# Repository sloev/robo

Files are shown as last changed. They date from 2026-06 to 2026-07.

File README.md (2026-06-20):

# 🤖 BlockBot Dashboard

Welcome to the **BlockBot Dashboard**! This is a fun, visual way to build and program **anything you can imagine** using an **ESP32-S2 Mini** brain and motorized stepper muscles. 

It doesn't have to be a standard robot—you can build a **crane**, a **car**, a **catapult**, a **drawing machine**, a **conveyor belt**, or a **robotic arm**! As long as it uses the motors and sensors, you can bring it to life.

**[🌐 View the Live Dashboard Demo on GitHub Pages](https://sloev.github.io/robo/)** *(Note: Hardware connections are simulated in the web demo).*

The brain board acts as its own Wi-Fi hotspot. When you connect your phone, tablet, or computer to it, this modern dashboard pops up automatically—no internet needed!

---

## 🎨 The Three Awesome Modes

The dashboard splits the control into three visual modes. Tap the tabs at the top of the screen to switch between them:

### 🧩 1. Coding Mode (Workflow Creator)
This is your coding workspace! Click block buttons on the left to add command blocks. Drag them around to change their order, choose which motors to run, adjust speeds, and add wait times. 

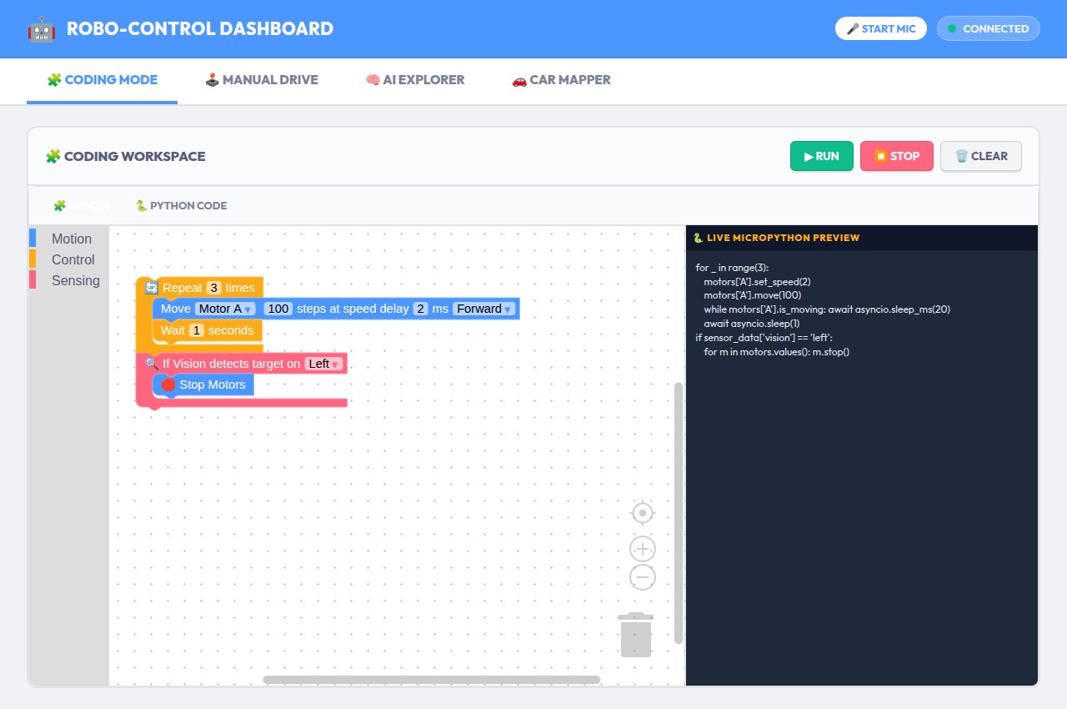
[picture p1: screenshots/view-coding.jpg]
Coding Mode in Action


**Senses & Command Blocks:**
*   **Set Motor Speed:** Adjust the speed delay of any motor on-the-fly.
*   **Stop Motors:** Instantly freeze all movement.
*   **If Vision tracks target:** Run blocks only if the camera sees your tracking marker in a certain area (Left, Center, Right).
*   **If Sound hears clap:** Run blocks only when the phone microphone detects a loud clap!

---

### 🕹️ 2. Manual Drive Mode (Steering Joysticks)
Drive your creation directly using virtual vertical joysticks! Slide them up or down to rotate cogs, move joints, or drive wheels, and release them to stop. The dashboard automatically builds a joystick for every motor you connect.

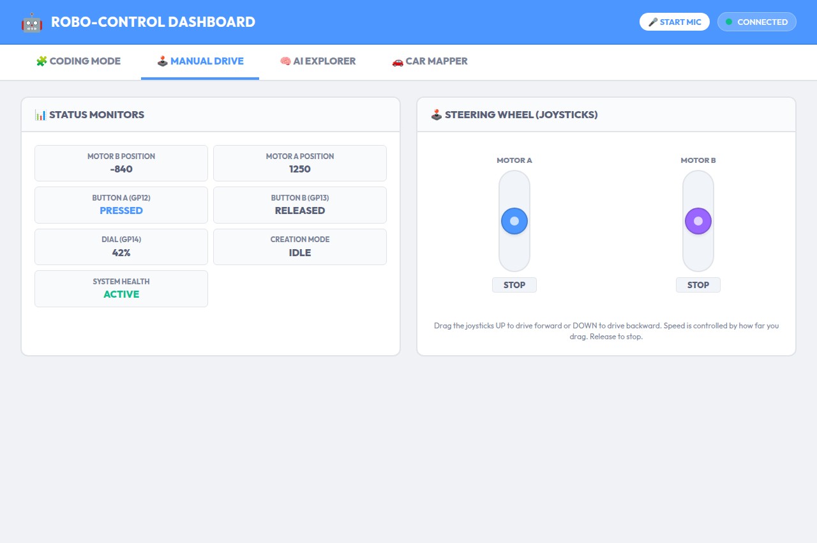
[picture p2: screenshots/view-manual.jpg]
Manual Drive in Action


---

### 🧠 3. Autonomous AI (Car Mode)
This is where the magic happens! Turn your stepper motor creation into an autonomous self-driving car using your phone's built-in sensors. By clamping your phone vertically to the front of the chassis using elastic bands and the ultra-discreet **Portrait Phone Clamp**, your phone acts as the robot's eyes, ears, and inner ear!

1.  **Sensor Fusion (Dead Reckoning):** The dashboard creates a sensor fusion of the phone's internal gyroscope, accelerometer, and magnetometer to understand its odometry and heading entirely on its own!
2.  **Learning Mode (Kinematic Discovery):** The robot wiggles its motors and uses the phone's sensors to reverse-engineer its own kinematics (whether it's built as a differential drive or an Ackermann steering setup).
3.  **Autonomous Mapping:** Place the car in the room and start the Live Mode. As the car wanders around, it uses the camera and IMU to dynamically create a live 2D map overlay of its environment.
4.  **Vision & Audio Navigation:** Using lightweight TensorFlow.js models running purely offline in the PWA, the phone actively detects obstacles using the front/rear cameras, and can react to loud noises or even utter simple sounds when encountering sudden movements or blockages!

Because all the heavy machine-learning and sensor processing happens in the browser on your powerful smartphone, the ESP32-S2 is freed up to focus entirely on perfect stepper motor coordination!

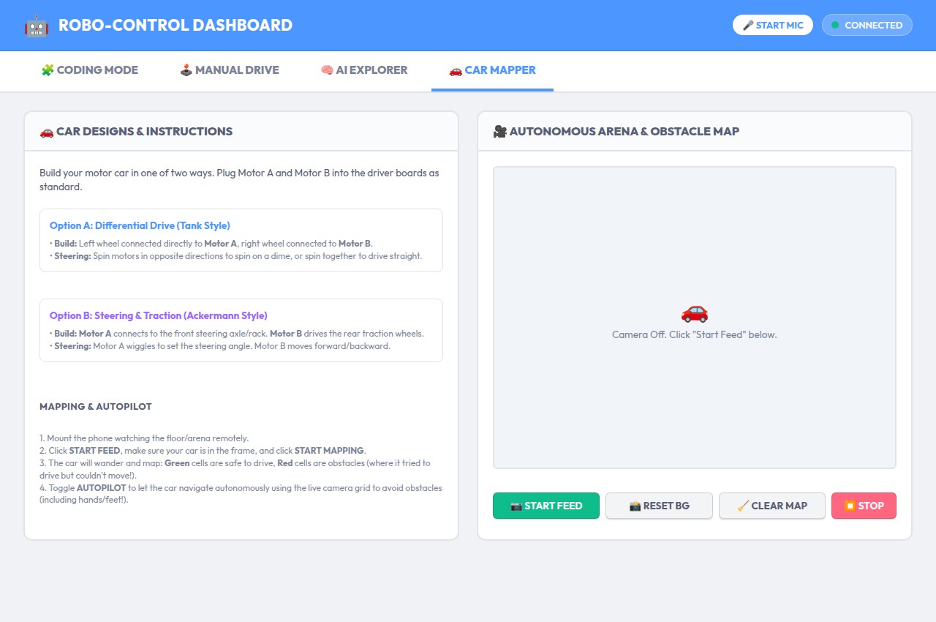
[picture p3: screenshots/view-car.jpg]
AI Car Mode in Action


---

## 🔌 How to Wire Your Creation

Here is a nice, color-coded map showing how all the parts plug together. 

```mermaid
graph TD
    %% Define Styles
    classDef esp32 fill:#4c97ff,stroke:#0d47a1,stroke-width:2px,color:#ffffff;
    classDef driver fill:#0fbd8c,stroke:#00796b,stroke-width:2px,color:#ffffff;
    classDef motor fill:#9966ff,stroke:#6a1b9a,stroke-width:2px,color:#ffffff;
    classDef power fill:#ffab19,stroke:#ff6f00,stroke-width:2px,color:#ffffff;
    classDef capacitor fill:#ff6680,stroke:#c2185b,stroke-width:2px,color:#ffffff;

    %% Nodes
    USB_PB["🔋 USB Power Bank"]:::power
    ESP_S2["🤖 ESP32-S2 Mini <br>(The Brain)"]:::esp32
    CAP["⚡ Capacitor <br>(1000µF Buffer)"]:::capacitor
    
    DRV_A["🔌 Driver Board A <br>(ULN2003)"]:::driver
    DRV_B["🔌 Driver Board B <br>(ULN2003)"]:::driver
    
    MOT_A["⚙️ Stepper Motor A"]:::motor
    MOT_B["⚙️ Stepper Motor B"]:::motor

    %% Connections
    USB_PB -->|USB-C Cable| ESP_S2
    
    ESP_S2 -->|GP1, GP2, GP3, GP4| DRV_A
    ESP_S2 -->|GP5, GP7, GP9, GP11| DRV_B
    
    ESP_S2 -->|"5V Pin (Power Out)"| CAP
    ESP_S2 -->|"GND Pin"| CAP
    
    CAP -->|VCC / GND| DRV_A
    CAP -->|VCC / GND| DRV_B
    
    DRV_A -->|5-Pin Plug| MOT_A
    DRV_B -->|5-Pin Plug| MOT_B
```

### ⚠️ A Rule for the Power Buffer (Capacitor)
Motors consume a lot of electricity in quick pulses. This can cause the ESP32 brain to reset (restart). 
*   **The Fix:** You must connect a **1000uF Electrolytic Capacitor** across the 5V and GND rails.
*   *⚠️ Crucial:* The capacitor is polarized! Solder the **longer lead (+)** to the 5V power line and the **lead with the white stripe (-)** to the GND line.

---

### ⚡ The "Minimum Version" (No Protoboard, No Capacitor!)
If you want to build the absolute simplest version of this project, you don't even need the capacitor or a protoboard! You can wire the components directly together:
1. Solder standard dupont jumper wires directly from the ESP32-S2's `5V` and `GND` pins to the `+` and `-` power pins on **both** ULN2003 driver boards.
2. Wire the control pins directly (GP1-4 to Driver A, GP5-11 to Driver B).
3. Plug in the Steppers.
4. Power the ESP32-S2 directly using a **USB Power Bank**. 
*Note: Because you don't have a smoothing capacitor, running both motors at maximum speed simultaneously might occasionally cause the ESP32 to brown-out and reset, but it works perfectly for most simple builds and learning!*

---

## 🏎️ The Custom 3D Printed Chassis

Check out our fully integrated Lego-compatible chassis design. The CI automatically renders this from our parametric OpenSCAD source directly into Slicer-ready assets!

### Fully Assembled
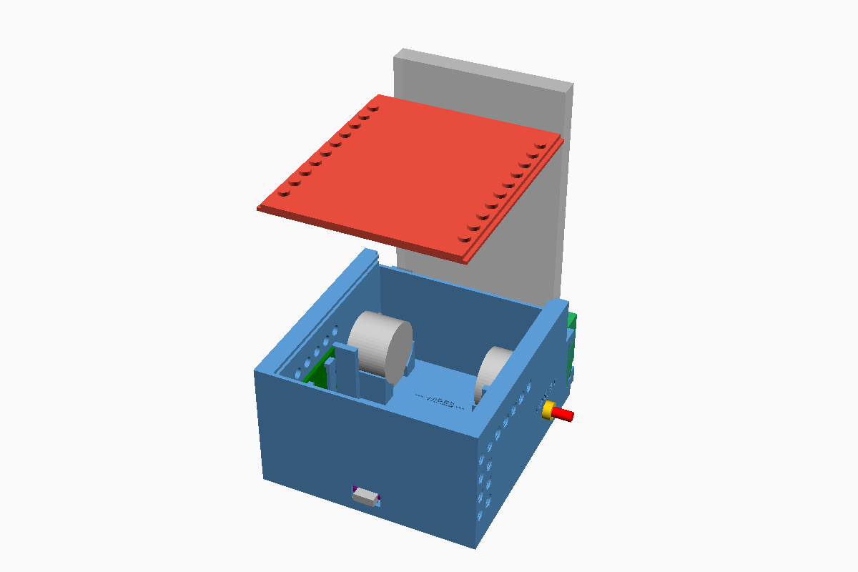
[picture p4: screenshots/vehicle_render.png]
Lego Robot Vehicle Chassis


### Individual Components
<div align="center">
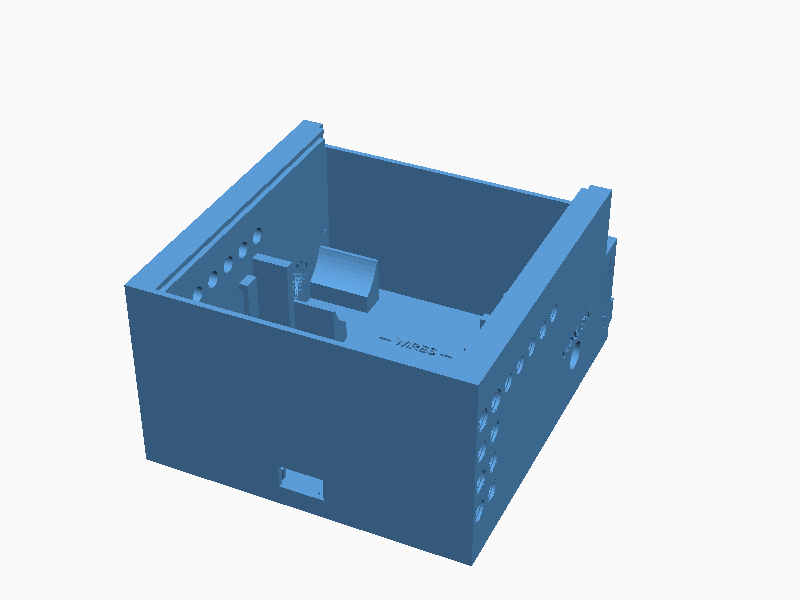
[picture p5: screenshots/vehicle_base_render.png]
  
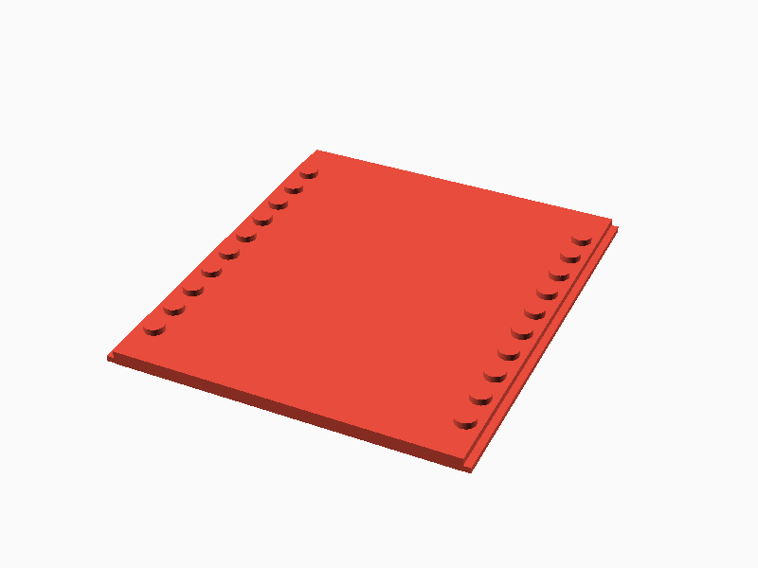
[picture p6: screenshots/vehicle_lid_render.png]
  
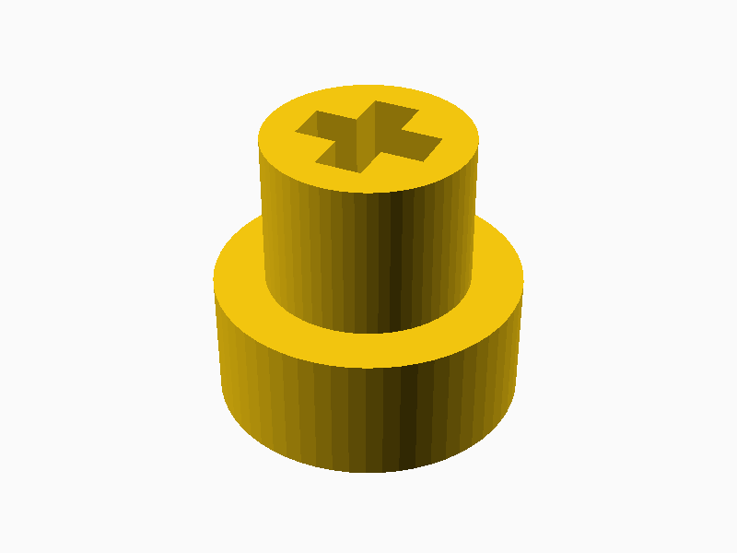
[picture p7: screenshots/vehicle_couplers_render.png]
  
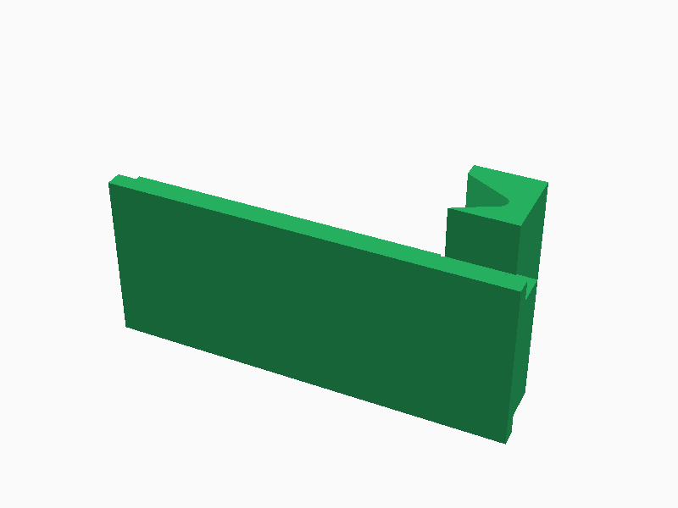
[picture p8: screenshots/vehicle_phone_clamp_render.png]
  
</div>

**Download the latest auto-generated 3D Models:**
* [📦 Download All Models (.zip)](https://github.com/sloev/robo/raw/master/vehicle_models.zip)
* [⬇️ Chassis Base (.stl)](https://github.com/sloev/robo/raw/master/vehicle_base.stl)
* [⬇️ Sliding Lid (.stl)](https://github.com/sloev/robo/raw/master/vehicle_lid.stl)
* [⬇️ Captive Couplers (.stl)](https://github.com/sloev/robo/raw/master/vehicle_couplers.stl)
* [⬇️ Portrait Phone AI Clamp (.stl)](https://github.com/sloev/robo/raw/master/vehicle_phone_clamp.stl)

---

## 🛠️ Step-by-Step Build Guide

1.  **Mount the Motors:** Screw your **28BYJ-48 stepper motors** into your custom cardboard, wood, or 3D-printed creation (e.g. wheels for a car, a pulley spool for a crane, or a launching arm for a catapult).
2.  **Solder the Power Rails:** Build a shared 5V line and GND line on a solderable perfboard. Solder the capacitor across them (mind the positive/negative directions!).
3.  **Connect the Brain & Drivers:** Connect the ESP32-S2's **5V** and **GND** pins to the power rails. Connect the power pins of the ULN2003 drivers to the same rails.
4.  **Control Wires:** Connect driver inputs to ESP32 pins:
    *   Motor A: GPIO **1, 2, 3, 4**
    *   Motor B: GPIO **5, 7, 9, 11**
5.  **Plug in Motors:** Plug the stepper motor cables directly into their driver boards.

---

## 🔌 Connecting Extra Senses (Sensors & Switches)

You can easily expand your creation's senses by connecting buttons, switches, dials, and other simple sensors directly to the ESP32-S2 Mini. The system has built-in support for digital and analog inputs!

### 🔘 1. Buttons & Switches (Digital Sensors)
You can connect buttons or toggle/micro-switches to **GPIO 12 (Button A)** and **GPIO 13 (Button B)**.
*   **Wiring:** Connect one leg of the button/switch to the GPIO pin (GP12 or GP13) and the other leg to **GND**.
*   **How it works:** The board uses internal pull-up resistors, keeping the signal `HIGH` (released) by default. When pressed/toggled, it connects to GND, pulling the signal `LOW` (pressed).
*   **Coding Mode:** Use the `If Button [A/B] is [Pressed/Released]` blocks to create conditional behaviors (e.g., *"If Button A is Pressed, then Move Motor A by 500 steps"*).

### 🎛️ 2. Dials & Potentiometers (Analog Sensors)
Connect an analog dial (potentiometer, e.g., 10kΩ) to **GPIO 14** to adjust speeds, thresholds, or angles.
*   **Wiring:** 
    *   Connect the **left pin** to **GND**.
    *   Connect the **right pin** to the ESP32's **3.3V pin** (do NOT use 5V for analog signals!).
    *   Connect the **middle pin (wiper)** to **GPIO 14**.
*   **How it works:** Turning the dial changes the voltage from 0V to 3.3V. The brain's Analog-to-Digital Converter (ADC) reads this and scales it from `0%` to `100%`.
*   **Coding Mode:** Use the `If Dial is [Greater than / Less than / Equal to] [X]%` block to trigger movements at specific dial positions (e.g., *"If Dial is Greater than 80%, then Stop Motors"*).

### 🍎 3. More Low-Hanging Fruits (Easy Upgrades)
Because the inputs are standard digital and analog pins, you can connect many other cheap sensors:
*   **Infrared Line/Obstacle Sensors (TCRT5000):** These have a digital output that behaves exactly like a button. Connect their `OUT` pin to **GP12** or **GP13**. When they detect a line or object, they pull the signal low—triggering your `If Button is Pressed` block!
*   **Light Sensors (LDR Photoresistors):** Build a simple voltage divider with a photoresistor and a 10k resistor. Connect the output to **GP14**. The light level will show up on your dashboard as the **Dial** percentage, letting you code light-sensitive creations (e.g., *"If Dial is Less than 30% [it's dark], then Move Motor A"*).
*   **Limit/Micro-Switches:** Wire these to GP12/GP13 just like buttons. Perfect for creating a crane that automatically stops winding when the carriage hits a physical limit switch!

---

## 🚀 Run the Code

1.  Install flashing tools on your computer: `make install-tools`
2.  Upload all files to the ESP32: `make upload`
3.  Reset the board to start: `make reset`
4.  Connect your phone's Wi-Fi to the network **"BlockBot"**, open `http://robot.com` and start creating!

💡 **Pro-Tip (Offline AI Autonomy):** To unleash the full power of the offline TensorFlow.js models, first open the **[Live Dashboard Demo](https://sloev.github.io/robo/)** on your phone using your normal internet connection, and "Install" it to your homescreen as an app. Then, switch your Wi-Fi to **"BlockBot"** and open the installed app. It will securely proxy through the robot's captive portal, allowing you to run heavy AI computations on your phone while controlling the ESP32!

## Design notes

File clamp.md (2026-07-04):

# Phone Clamp — Source of Truth

The horizontal phone clamp for the BlockBot chassis. **Read this before touching any
clamp geometry.** It went through ~10 wrong iterations; the constraints below are the
lessons from each. **When in doubt, don't trust this file's numbers over the code —
verify with the checks in "Verifying a change" below.** Iteration #9 was this doc and
the code silently drifting apart: a later edit shrank the T-slot cavity and dropped
the rail extension but never updated the tongue to match, so the shipped tongue
reached 20mm past the cavity into solid wall. Iteration #10 was fixing that collision
by raising the grip finger to clear the V-lip shelf, without checking whether the
finger was still *connected* to the rest of the tongue below its new floor -- it
wasn't, for a 2mm Z-band, so the finger printed as an unsupported floating island.
"Zero collision" and "prints without support" are two different checks; both are in
"Verifying a change" now.

## The core idea

The phone stands **in front of the chassis front wall** (NOT on top, NOT inside).
It leans back against the wall's front face (y=58). Two V-jaws grip its left/right
side edges. A rubber band stretches between the forward-facing pegs on each jaw,
across the phone's front face — fully visible and accessible.

```
                  rubber band (y≈78, z=14)
         ●────────────────────────────────●
         │      phone front face (y=67)   │
   ┌─────┴──────────────────────────────┴─────┐
   │  L jaw           phone body        R jaw │  ← jaws V-grip side edges
   │  (fixed)                         (slide) │
═══╪══════════════════════════════════════════╪═══  ← clamp-wall y=48-58 (10mm)
   │ T-slot on front face (y=54-58 neck, y=51-54 undercut)
   │ No rail extension — slot spans the full chassis width (x=-10..+48)
   │
   gap y40-48 (cavity: motors clear of all clamp geometry)
```

## Shared constants (`lego_robot_common.scad`)

The T-slot cavity bounds and print tolerance live in ONE place and are referenced
by both `lego_robot_base.scad` (cavity cuts) and `lego_robot_phone_clamp.scad`
(tongue sizing), specifically to prevent the two from drifting apart again:

| Constant | Value | Meaning |
|---|---|---|
| `clamp_tol` | 0.3mm | Per-side print clearance for the sliding tongue fit |
| `slot_x0` / `slot_x1` | -10 / 48 (`width/2`) | T-slot cavity X span |
| `slot_neck_z0/z1` | 10 / 29 | Neck cavity Z span (jaw slides here) |
| `slot_uc_z0/z1` | 7 / 32 | Undercut cavity Z span (T-flange lock) |
| `shelf_top_z` | 8 | V-lip shelf top surface — jaw geometry must clear this |
| `band_peg_z` | 14 | Shared Z height for both band pegs. Must clear the moving jaw's finger floor (`slot_neck_z0 + clamp_tol` = 10.3) by enough for the d=4 peg shaft (radius 2) to stay embedded in it -- not just "above the shelf" (8.3), which left the peg floating. |

## Geometry (mm, OpenSCAD coordinates)

`fy = length/2 = 48` (chassis front wall inner face).

| Feature | Where | Notes |
|---|---|---|
| Clamp-wall | `[0,53,18]` cube `[96,10,36]`, centered | x=-48..+48, y=48-58, z=0-36. Carries T-slot on front face. No rail extension. |
| V-lip shelf | center `[0,60,4]` cube `[92,16,8]` | x=-46..+46, y=52-68, z=0-8. Phone bottom rests here. |
| V-lip groove | `[-46,60,8]` rot[0,90,0] extrude 92, `rounded_notch_2d(tip_x=4, base_x=0, half_width=5, r=1)` | x=-46..+46. Narrows in Y, self-centres thickness. Opens up → no support. Tip rounded, 4mm deep (was a 5mm-deep sharp point) so 4mm of shelf remains below it instead of 3mm. |
| T-slot neck | `[slot_x0,54,slot_neck_z0]` cube `[58,4,19]` | x=-10..+48, y=54-58, z=10-29. Jaw neck slides here. |
| T-slot undercut | `[slot_x0,51,slot_uc_z0]` cube `[58,3,25]` | x=-10..+48, y=51-54, z=7-32. Tongue fills here — jaw can't pull out in Y. |
| Fixed jaw (left) | finger `[-40,61.5,21.5]` cube `[10,15,29]` | x=-45..-35, y=54-69, z=7-36. Fused to chassis. |
| Fixed jaw V-notch | `rounded_notch_2d(tip_x=-42, base_x=-35, half_width=4.5, r=1.2)` translate `[0,62.5,6]` extrude 35 | Tip at x=-42 (was -44), base at x=-35 (inner face). Spans y=58-67 (phone thickness). Tip rounded and pulled in from the finger's outer face (x=-45) to leave 3mm of backing material instead of 1mm. |
| Fixed band peg | `[-40,68,band_peg_z]` rot[-90,0,0] cyl d4 h5 + d7 head | Forward-facing (+Y). Visible/accessible from front. |
| Moving jaw (right) | separate part, `lego_robot_phone_clamp.scad` | Mirror geometry at x=+40 |
| Moving jaw tongue | x = `slot_x0+clamp_tol` .. `slot_x1-clamp_tol` (≈-9.7..47.7) | Neck z=10.3-28.7, y=53.6-58.5; full undercut z=7.3-31.7, y=51.3-53.7. Always inside the T-slot cavity — never size or position this independently of `slot_x0`/`slot_x1`. |
| Moving jaw grip finger | `[35,58.3,10.3]` cube `[10,11,25.7]` | Held `clamp_tol` off the wall face (y=58). Floored at `slot_neck_z0 + clamp_tol` (not `shelf_top_z + clamp_tol`) so it's flush with the neck's own floor -- no gap, no floating island, and it clears the shelf with even more margin than the minimum. |
| Moving jaw band peg | `[40,68.3,band_peg_z]` rot[-90,0,0] | Matches fixed peg (offset by the finger's `clamp_tol` standoff). `band_peg_z` sized so the peg shaft stays inside the (now taller-floored) finger. |

## Hard constraints (each is a past bug — do not regress)

1. **T-slot is on the WALL FRONT FACE, not through the wall.** Neck y=54-58 (4mm),
   undercut y=51-54 (3mm), leaving 3mm solid wall at back (y=48-51). Never cut
   past y=48 = cavity boundary.
2. **T-profile is mandatory.** A rectangular slot lets the jaw pull straight out in Y.
   The tongue fills the FULL undercut height (`slot_uc_z0`-`slot_uc_z1`) — not just
   two flanges.
3. **The moving jaw's tongue X span must be derived from `slot_x0`/`slot_x1`
   (minus `clamp_tol`), never hardcoded independently.** There is no rail
   extension — the whole T-slot cavity is `slot_x0..slot_x1`. A tongue sized or
   positioned outside that range collides with solid, un-milled wall (this
   shipped once: 20mm of tongue inside solid material, ~2.8cm³ of interference).
4. **V-notch base is flush with the jaw inner face (x=±35).** No flat wall between
   the notch base and the jaw edge. Fixed jaw tip at x=-42, moving jaw tip at x=+42
   (both via the shared `rounded_notch_2d()` in lego_robot_common.scad, r=1.2).
   Keep the tip at least ~3mm off the finger's outer face (x=∓45) -- a past version
   put it only 1mm off with a sharp point, both a thin wall and a stress
   concentrator right behind it, prone to snapping under a side load.
5. **Band pegs are on the jaw FRONT FACES, visible and accessible.** Not buried in
   the cavity. Forward-facing (rotate([-90,0,0])) so the rubber band hooks on and
   stretches across the phone front. No off-axis pull. Both pegs share `band_peg_z`.
6. **V-lip shelf carries phone weight; V-notches are pure vertical prisms.**
   Jaw bottoms must not catch the phone, and any moving-jaw solid crossing the
   shelf's footprint (x<=46, y<=68) must stay at or above `shelf_top_z + clamp_tol`.
7. **Everything prints support-free.** V-grooves open upward; T-slot cuts are
   straight horizontal channels; tongue profile is symmetrical. Any feature you
   raise/move to fix a collision must still be *connected* to the rest of the part
   below its new floor -- fixing a collision by raising something can silently
   turn it into a floating island (iteration #10).
8. Both parts render `Volumes: 2` (a single connected solid each). Validate with
   `./ci_render_part.sh`.

## Verifying a change

`Volumes: 2` only proves each part is manifold on its own. It does NOT prove the two
parts don't collide with each other, and it does NOT prove a part prints without
support. Both need separate checks:

**1. Collision between parts** — boolean them together and confirm the intersection
is empty:

```
openscad -o /tmp/collision.stl - <<'EOF'
use <lego_robot_base.scad>
use <lego_robot_phone_clamp.scad>
intersection() { vehicle_base(); phone_clamp_jaw(); }
EOF
```

`Current top level object is empty` = no collision. Any exported geometry means the
two parts physically overlap and cannot be assembled as printed.

**2. Floating/unsupported regions within one part** — slice it into thin horizontal
slabs across its full Z range and watch `Volumes:` in the OpenSCAD output. A jump
from `Volumes: 2` (or empty) at one Z to `Volumes: 3+` where the *new* piece has no
material in the slab just below it is an unsupported region (a piece that was
already connected lower down and simply continues upward alone is fine -- check
where a piece *first* appears, not every slice it appears in):

```
for z in 7 9 11 13 ...; do
  openscad -o /tmp/slice.stl - <<EOF
use <lego_robot_phone_clamp.scad>
intersection() { phone_clamp_jaw(); translate([-50,0,$z]) cube([150,100,0.05]); }
EOF
done
```

This is how iteration #10 (the floating grip finger) was actually found -- the
finger looked fine in isolation and passed the collision check, but a slice at
z=9 showed it as a disconnected island with nothing underneath.

## Loading sequence

1. Telescope moving jaw right to load the phone (only the finger + band peg are
   visible/accessible outside the chassis footprint; the tongue stays inside the
   T-slot cavity throughout).
2. Hook rubber band on fixed jaw peg (now fully accessible, moving jaw is out).
3. Place phone against wall (y=58), bottom edge in V-groove.
4. Slide moving jaw left until V-notch grips phone's right edge.
5. Hook rubber band on moving jaw peg — tension holds both jaws closed.

## Files that must stay in sync

- `lego_robot_common.scad` — shared T-slot constants (`slot_x0/x1`, `clamp_tol`, etc).
- `lego_robot_base.scad` — clamp-wall, shelf, V-groove, T-slot cuts, fixed jaw, fixed band peg.
- `lego_robot_phone_clamp.scad` — moving jaw (finger + T-tongue + band peg), all sized from the shared constants.
- `lego_robot_showcase.scad` — band at `[0, length/2+28, 10]`; phone at `[0, length/2+14.5, 78]`.
- `website/viewer.js` — clamp exploded pos `[60, 30, 0]` (Three.js, jaw slides right).
- Coord map OpenSCAD→Three.js: `[x, y, z] → [x, z, -y]`.

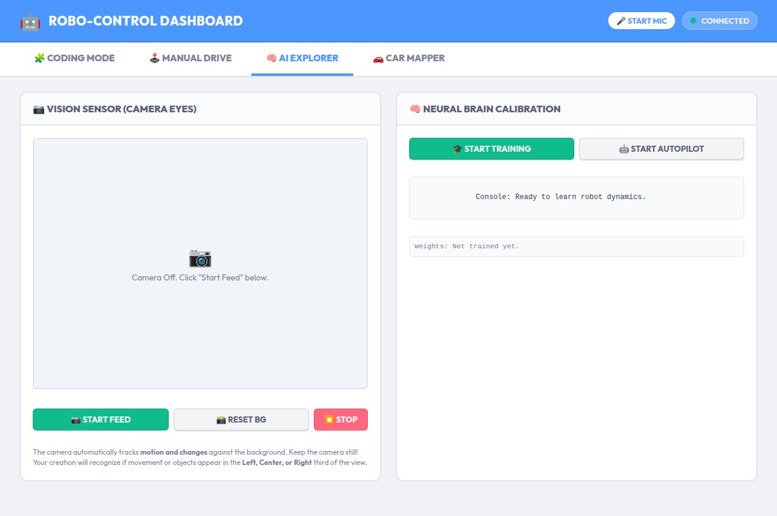
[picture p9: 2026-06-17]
screenshots/view-ai.jpg

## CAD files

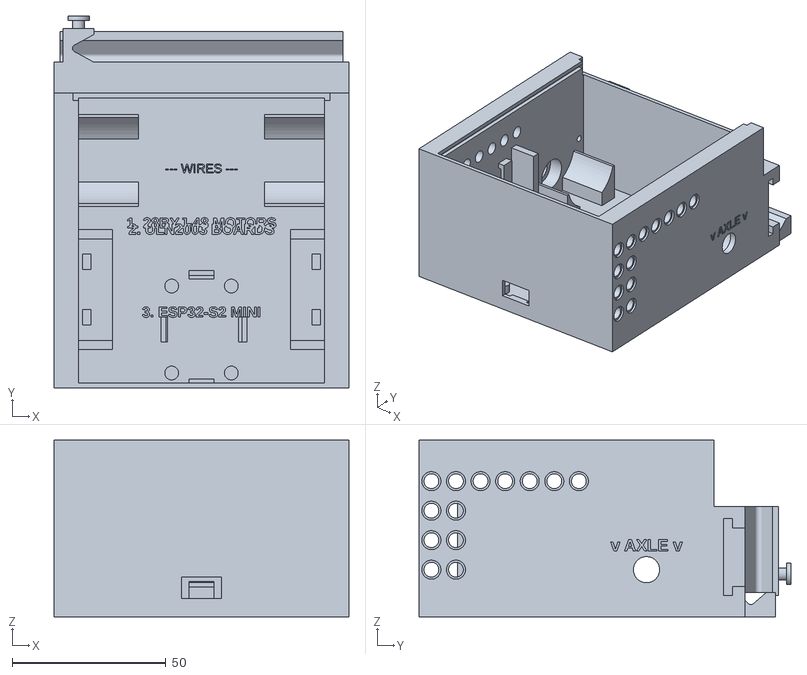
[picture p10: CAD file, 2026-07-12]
vehicle_base.stl
96.0 x 121.0 x 57.6

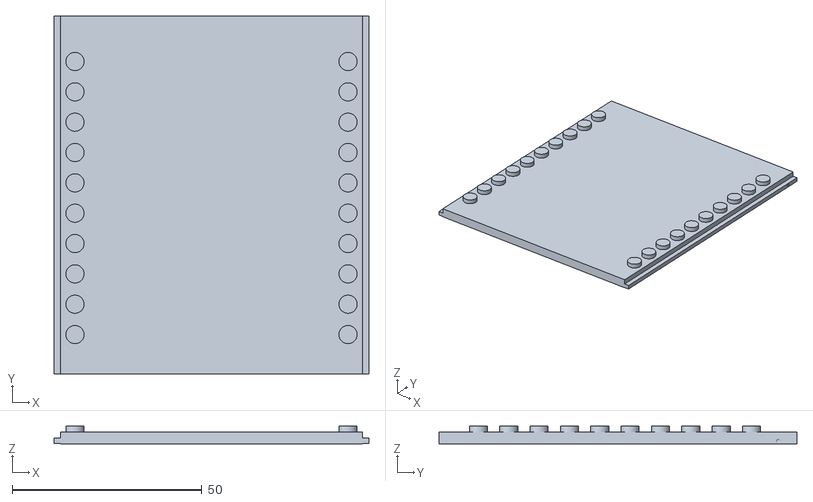
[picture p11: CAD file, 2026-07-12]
vehicle_lid.stl
83.0 x 94.4 x 4.70

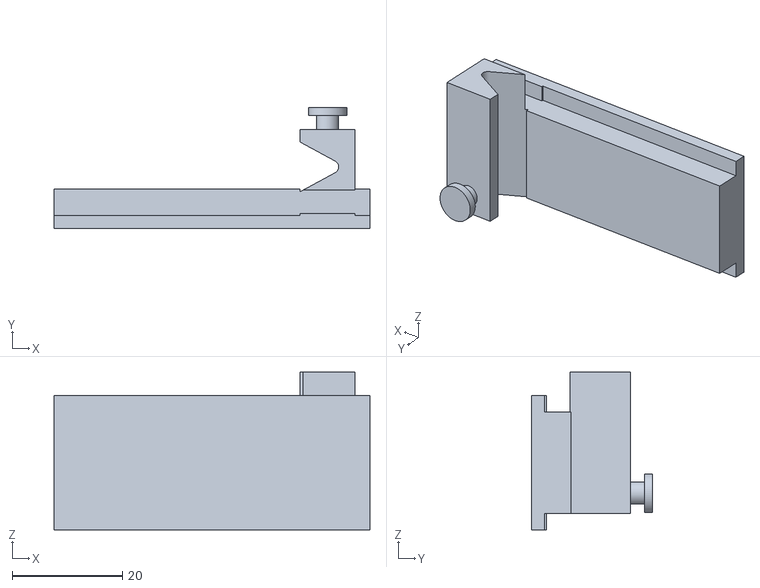
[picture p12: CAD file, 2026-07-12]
vehicle_phone_clamp.stl
57.4 x 22.0 x 28.7

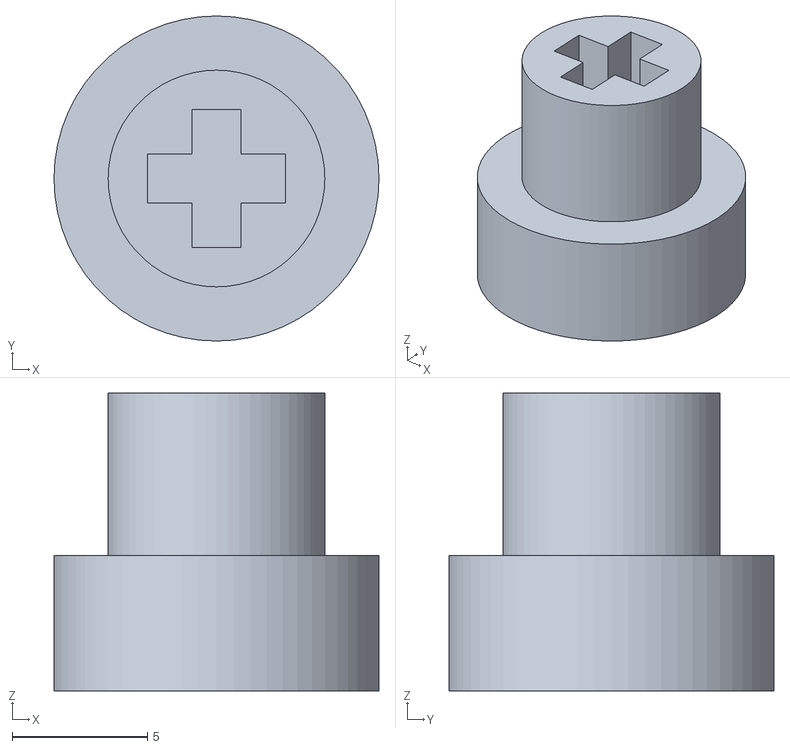
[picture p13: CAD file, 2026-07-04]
vehicle_couplers.stl
12.0 x 12.0 x 11.0

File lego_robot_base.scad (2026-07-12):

include <lego_robot_common.scad>

module vehicle_base() {
    difference() {
        union() {
            base_shell();
            esp32_snap_tray();
            uln_wall_mount_left();
            mirror([1, 0, 0]) uln_wall_mount_left();
            motor_bays();

            // Friction detent bumps for the sliding lid
            translate([83.4/2, length/2 - 5, lid_z]) sphere(d=1);
            translate([-83.4/2, length/2 - 5, lid_z]) sphere(d=1);
            
            // Internal Assembly Instructions & Wire Routing Paths
            translate([0, motor_y - 22, floor_z - 0.1]) linear_extrude(0.7) text("1. 28BYJ-48 MOTORS", size=3.5, halign="center", font="Liberation Sans:style=Bold");
            translate([0, 2, floor_z - 0.1]) linear_extrude(0.7) text("2. ULN2003 BOARDS", size=3.5, halign="center", font="Liberation Sans:style=Bold");
            translate([0, -25, floor_z - 0.1]) linear_extrude(0.7) text("3. ESP32-S2 MINI", size=3.5, halign="center", font="Liberation Sans:style=Bold");
            
            translate([0, 22, floor_z - 0.1]) linear_extrude(0.7) text("--- WIRES ---", size=3, halign="center");
            
            // --- AI Phone Holder: phone stands IN FRONT of the chassis front wall ---
            // Single wide cube: clamp-wall (x=-48..+48) fused
            // into one piece.
            // T-slot is milled into the front face (y=58). Moving jaw telescopes right.
            translate([0, length/2 + 5, 18]) cube([96, 10, 36], center=true); // x=-48..+48, y=48-58, z=0-36
            // V-lip shelf: phone bottom rests in V-groove (cut below). 6mm overlap into
            // wall (y=52..58) so there is no T-junction at the wall front face (y=58).
            translate([0, length/2 + 12, 4]) cube([92, 16, 8], center=true);     // shelf y52-68, z0-8
            // Fixed LEFT jaw: V-notch grips phone left edge; fused to wall.
            // Jaw front (y=69) is 1mm past shelf front (y=68) — no coplanar face.
            difference() {
                translate([-40, length/2 + 13.5, 21.5]) cube([10, 15, 29], center=true); // y54-69, z7-36
                // V-notch: tip at x=-42, base flush with inner jaw face x=-35 (no flat wall).
                // Tip pulled in from the finger's outer face (x=-45) to leave 3mm of backing
                // material instead of 1mm, and rounded (not a knife edge) so there's no sharp
                // stress-concentrating point right behind that thin material -- a sharp V here
                // both had barely any material behind it and was prone to snapping under a
                // side load from the phone.
                translate([0, length/2 + 14.5, 6]) linear_extrude(35)
                    rounded_notch_2d(tip_x = -42, base_x = -35, half_width = 4.5, r = 1.2);
            }
            // Band peg on jaw front face — fully visible, hooked before phone is inserted.
            // Peg base is 1mm inside jaw body (y=68 < jaw front y=69) — no T-junction.
            translate([-40, length/2 + 20, band_peg_z]) rotate([-90, 0, 0]) {
                cylinder(d=4, h=5);
                translate([0, 0, 3.5]) cylinder(d=7, h=1.5);
            }
        }
        
        // --- CENTRALIZED CUTS ---
        
        // Lego Technic holes on the grid (5.8 + n*9.6), through the side WALLS
        // ONLY (h=12), Ø4.8 + Ø6.2x0.9 outer bevel. The top row (44.2) clears the
        // wall-mounted ULN boards (board top ~36); the lower rows are kept only
        // in the rear, behind the boards. The front motor zone stays solid.
        for (y = [-44 : 8 : 44]) {
            zs = (y < -30)            ? [15.4, 25.0, 34.6, 44.2]
               : (y < motor_y - 18)   ? [44.2]
               :                        [];
            for (z = zs) {
                translate([-44, y, z]) rotate([0, 90, 0]) cylinder(d=4.8, h=12, center=true);
                translate([ 44, y, z]) rotate([0, 90, 0]) cylinder(d=4.8, h=12, center=true);
                translate([-width/2, y, z]) rotate([0,  90, 0]) cylinder(d=6.2, h=0.9);
                translate([ width/2, y, z]) rotate([0, -90, 0]) cylinder(d=6.2, h=0.9);
            }
        }
        
        // V-lip groove centred in shelf (y=60): phone bottom self-centres. Opens up.
        // Tip pulled up from 5mm deep to 4mm (leaves 4mm of shelf below the groove
        // instead of 3mm) and rounded instead of a knife edge, for the same reason
        // as the jaw V-notches: less material and a sharp stress point right where
        // the phone's weight presses down.
        translate([-46, length/2 + 12, 8]) rotate([0, 90, 0])
            linear_extrude(92) rounded_notch_2d(tip_x = 4, base_x = 0, half_width = 5, r = 1);
        // T-slot milled into front face of clamp-wall. Bounds come from
        // lego_robot_common.scad so the moving jaw's tongue (sized from the
        // same constants) can never drift out of sync with this cavity.
        // Neck (4mm deep from front face, 19mm tall): jaws slide freely in X.
        translate([slot_x0, length/2 + 6, slot_neck_z0])
            cube([slot_x1 - slot_x0, 4, slot_neck_z1 - slot_neck_z0]); // x=-10..+48, y=54-58, z=10-29
        // Undercut (3mm deeper, 25mm tall): T-flanges lock tongue — can't pull out in Y.
        translate([slot_x0, length/2 + 3, slot_uc_z0])
            cube([slot_x1 - slot_x0, 3, slot_uc_z1 - slot_uc_z0]);    // x=-10..+48, y=51-54, z=7-32
        
        // USB-C Pass-through (aligned with the ESP32's USB-C edge at the back)
        translate([0, -length/2, 9.5]) cube([13, 8, 7], center=true);
        
        // Motor coupler sockets + screw pilots (both side walls). Each wall gets:
        //  - a Ø12.5 circular pocket in the inner face the coupler's Ø12 ring
        //    drops into,
        //  - a Ø8.5 hole through the rest of the wall for the coupler's Ø8 nose
        //    and the LEGO axle (the Ø12 ring can't pass it => captive),
        //  - two Ø2.5 pilots (ears 35mm apart) the motor screws into.
        // The motor mounts face-on to the wall; its shaft enters the coupler.
        for (s = [-1, 1]) {
            translate([s*40, motor_y, shaft_z]) rotate([0, s*90, 0]) cylinder(d=12.5, h=5.5);
            translate([s*40, motor_y, shaft_z]) rotate([0, s*90, 0]) cylinder(d=8.5, h=12);
            for (dy = [-17.5, 17.5])
                translate([s*40, motor_y + dy, motor_z]) rotate([0, s*90, 0]) cylinder(d=2.5, h=7);
        }

        // External Axle Hole Indicators (0.5mm indented into outer walls)
        translate([-width/2 + 0.5, motor_y, shaft_z + 6]) rotate([90, 0, -90]) 
            linear_extrude(1) text("v AXLE v", size=4, halign="center", font="Liberation Sans:style=Bold");
        translate([width/2 - 0.5, motor_y, shaft_z + 6]) rotate([90, 0, 90]) 
            linear_extrude(1) text("v AXLE v", size=4, halign="center", font="Liberation Sans:style=Bold");
    }
}


module base_shell() {
    difference() {
        // Outer Body
        translate([0, 0, height/2]) cube([width, length, height], center=true);

        // Inner cavity. The long SIDE walls are a full LEGO unit (side_wall = 8mm)
        // thick, so the lid (79.6mm) slides into a real 1-unit wall and the
        // Technic holes / motor mounts sit in solid material. The end walls stay
        // thin (wall_t) to leave length for the motors and electronics.
        translate([0, 0, floor_z + height/2])
            cube([width - 2*side_wall, length - 2*wall_t, height], center=true);

        // (No bottom Lego cavity: a flat solid underside prints flat on the bed
        // with no support and a strong floor, instead of bridging a recess.)

        // Rear Wall Cutaway for Sliding Lid (open at the top to avoid a fragile bridge)
        translate([0, length/2, height - 1.6])
            cube([83.5, 5, 10], center=true);

        // Inner Side Grooves for Lid Rails (Z=44.8 to 46.4). Open at the front
        // for the lid to slide in, but stopped before the back (USB-C) wall so
        // it never cuts a slit through it -- the solid back wall is the lid stop.
        translate([0, 2.4, lid_z])
            cube([83.4, length - 1.2, 1.8], center=true);
    }
}
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

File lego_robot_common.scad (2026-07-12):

/* 
 * Parametric Lego-Compatible Robotic Vehicle Enclosure
 * Completely self-contained OpenSCAD script.
 */

$fn = 60;

// --- LEGO & ENCLOSURE PARAMETERS ---
lego_pitch = 8.0;
lego_height = 9.6;
wall_t = 1.6;        // thin end walls (front/back) for electronics clearance
side_wall = 8.0;     // long side walls: a full LEGO unit so the lid seats and
                     // Technic holes/motor mounts sit in solid wall

// Outer Dimensions. Shorter + taller (reorg): the ULN2003 boards stand on the
// inner side walls and the ESP32 lies between them, so the floor needs less
// length; the extra height lets the phone clamp grip higher.
box_w_lu = 12; // 96.0 mm (Outer Width)
box_l_lu = 12; // 96.0 mm (Outer Length, shortened from 128)
box_h_lh = 6;  // 57.6 mm (Outer Height, raised from 48)

width = box_w_lu * lego_pitch;
length = box_l_lu * lego_pitch;
height = box_h_lh * lego_height;

lid_t = 3.2; // Sliding lid thickness
floor_z = 4.8; // 3.2mm Lego tube cavity + 1.6mm floor
lid_z = height - 2.4; // centre Z of the sliding-lid rail groove (just below top)

// --- ALIGNED INTERNAL POSITIONS ---
// The motors are mounted rolled 180 degrees about their body long axis so the
// off-centre 28BYJ-48 shaft points DOWN, not up. That drops the axle low enough
// to drive wheels directly off the couplers. shaft_z is snapped to the lowest
// LEGO Technic hole row (5.8 + 9.6) so the axle line sits on the wall grid.
shaft_z = 15.4; // motor shaft / coupler height (lowest Technic row: 5.8 + 9.6)
motor_y = 26.0; // front; keeps the front mounting ear (motor_y+17.5) inside the cavity
motor_z = shaft_z + 8.0; // body axis sits 8mm ABOVE the shaft (motor rolled shaft-down)

// ULN2003 board holder centre Y (shared by uln_wall_mount_left() and the
// showcase's drawn board, so the drawn board can't drift out of the holder
// again -- see lego_robot_base.scad's uln_wall_mount_left() comment).
uln_uy = -16;

// --- PHONE CLAMP T-SLOT (shared by the base cavity + the moving jaw tongue) ---
// Keeping these numbers in one place stops the two parts drifting out of
// sync -- a past edit shrank the cavity without updating the tongue to
// match, letting the tongue reach 20mm past the cavity into solid wall.
clamp_tol    = 0.3;        // per-side print clearance for the sliding tongue fit
slot_x0      = -10;        // T-slot cavity start (chassis X)
slot_x1      = width / 2;  // T-slot cavity end == chassis half-width
slot_neck_z0 = 10;  slot_neck_z1 = 29;  // neck cavity Z range (jaw slides here)
slot_uc_z0   = 7;   slot_uc_z1   = 32;  // undercut cavity Z range (T-flange lock)
shelf_top_z  = 8;          // V-lip shelf top surface -- jaw geometry must clear this
// Shared Z height for both band pegs (keeps rubber band level). Must clear
// the moving jaw's grip finger floor (slot_neck_z0 + clamp_tol = 10.3) by
// enough for the d=4 peg shaft (radius 2) to stay embedded in it.
band_peg_z   = 14;

// --- STRUCTURAL HELPERS ---
// V-notch/groove with a rounded (filleted) tip instead of a sharp point.
// A sharp interior point is a stress concentrator, and printing it thin
// leaves almost no backing material behind it -- both make the V prone to
// snapping under a side load. hull() of a real circle at the tip with two
// near-zero-radius circles at the base corners gives sharp base corners
// (needed where the notch must sit flush against a flat face) and a smooth
// fillet at the tip, entirely automatically (no manual tangent-angle math).
// The tip still reaches exactly to tip_x, same as an unrounded V would --
// call this with a shallower tip_x than a knife-edge design to actually gain
// backing material, not just a rounded version of the same knife edge.
module rounded_notch_2d(tip_x, base_x, half_width, r) {
    hull() {
        translate([tip_x + r * sign(base_x - tip_x), 0]) circle(r = r);
        translate([base_x, half_width]) circle(r = 0.01);
        translate([base_x, -half_width]) circle(r = 0.01);
    }
}

// --- RENDER TARGET ---

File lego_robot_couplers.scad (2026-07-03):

include <lego_robot_common.scad>

// Motor coupler: maps the 28BYJ-48 flat-D shaft to a standard LEGO Technic
// cross axle. Profile is Ø12 at the motor (captive) end stepping DOWN to Ø8 at
// the axle end, so it prints standing on the wide end (widest -> narrowest, no
// overhang) while the Ø12 ring stays captive behind the chassis wall and the
// Ø8 nose pokes out through the Ø8.5 hole.
module motor_coupler() {
    difference() {
        union() {
            // Motor/captive end (Ø12) and axle nose (Ø8), axis along X.
            translate([3.0, 0, 0])  rotate([0, 90, 0]) cylinder(d=12, h=5, center=true);
            translate([-2.5, 0, 0]) rotate([0, 90, 0]) cylinder(d=8,  h=6, center=true);
        }

        // 28BYJ-48 flat-D shaft socket (motor end, +X): Ø5.2 with two flats 3mm
        // apart. The flat cuts are nested in a LOCAL difference with the socket
        // cylinder so they only shape the socket -- never cut the coupler body.
        translate([3.0, 0, 0]) difference() {
            rotate([0, 90, 0]) cylinder(d=5.2, h=5.5, center=true);
            translate([0,  2.5, 0]) cube([8, 2, 6], center=true);
            translate([0, -2.5, 0]) cube([8, 2, 6], center=true);
        }

        // LEGO Technic cross-axle socket (axle end, -X).
        translate([-3.0, 0, 0]) rotate([0, 90, 0]) {
            cube([5.1, 1.8, 5.5], center=true);
            cube([1.8, 5.1, 5.5], center=true);
        }
    }
}

// Color applied for individual render view. Standalone export only: rotated
// so the module's own natural axis-along-X orientation (needed by
// lego_robot_showcase.scad, which places it against the chassis wall) prints
// standing on its wide end instead of lying on its side -- see the comment
// above. Lying on its side turns the shaft/axle sockets into horizontal
// holes needing support; standing, the whole part is support-free.
color("#f1c40f") rotate([0, 90, 0]) motor_coupler();

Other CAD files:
lego_robot_enclosure.scad
lego_robot_lid.scad
lego_robot_phone_clamp.scad
lego_robot_showcase.scad
lego_robot_vehicle.scad
patch_motors.scad
patch_uln.scad

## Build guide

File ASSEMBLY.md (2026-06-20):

# 🛠️ BlockBot General Assembly Instructions

Welcome to the general assembly guide for BlockBot! This guide covers the core physical build.

## Prerequisites
1. Ensure you have downloaded the `vehicle_models.zip` from the repository.
2. 3D Print all parts (`vehicle_base.stl`, `vehicle_lid.stl`, `vehicle_couplers.stl`, `vehicle_phone_clamp.stl`) without supports.
3. Gather your electronics: ESP32-S2 Mini, two ULN2003 drivers, two 28BYJ-48 stepper motors, and a USB power bank.

## Step 1: Chassis Base & Motors
1. Slide your two 28BYJ-48 stepper motors into the internal `motor_bays` of the `vehicle_base` part. The wires should point upwards or inwards.
2. The motor mounting holes align with the tiny friction pegs inside the base. Press them firmly into place.
3. Attach the 3D-printed `vehicle_couplers` onto the flattened stepper motor shafts protruding from the sides.
4. Push standard Technic axles into the couplers, and attach your desired wheels or tracks!

## Step 2: Electronics Placement
1. Place the ESP32-S2 Mini into the `esp32_snap_tray` on the top deck of the chassis base. It will friction-snap in.
2. Place the two ULN2003 driver boards into the `uln2003_flat_tray` slots.
3. Wire the components according to the diagram in the [README.md](README.md). (Remember the 1000uF capacitor if using a single power supply!).

## Step 3: Sliding Lid
1. Once all wires are tucked in securely, take the `vehicle_lid` piece.
2. Align it with the top rails of the `vehicle_base`.
3. Slide it forward until it is completely flush and closes the enclosure. The top of the lid has Lego-compatible studs for further building!

## Step 4: Portrait Phone Clamp (For AI Autonomy)
If you want to use the Autonomous AI Car mode:
1. Rest the bottom edge of your smartphone on the front lip of the chassis base.
2. Take the tall `vehicle_phone_clamp` T-bar and insert its rail into the vertical T-slot located on the front wall of the chassis base.
3. Slide it down until the top jaw firmly grips the top edge of your phone.
4. Hook a rubber band onto the tiny peg on the left side of the sliding jaw, stretch it down, and hook it onto the peg on the left side of the chassis base. Repeat for the right side.
5. The elastic tension will constantly pull the slider down, locking the phone vertically and securely against the front wall!

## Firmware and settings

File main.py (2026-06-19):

import asyncio
import gc
from machine import Pin, ADC
from stepper import Stepper
from dns_server import DNSServer
from web_server import WebServer

# Pin Definitions (IN1, IN2, IN3, IN4 for each motor)
# Adjust these pins to match your physical wiring setup
MOTOR_PINS = {
    'A': [1, 2, 3, 4],
    'B': [5, 7, 9, 11]
}

# Initialize Stepper Motors
motors = {name: Stepper(pins) for name, pins in MOTOR_PINS.items()}

# Initialize Hardware Senses (Buttons/Switches with internal Pull-up)
btn_a = Pin(12, Pin.IN, Pin.PULL_UP)
btn_b = Pin(13, Pin.IN, Pin.PULL_UP)

# Initialize Hardware Senses (Analog Potentiometer / Dial)
pot = ADC(Pin(14))
pot.atten(ADC.ATTN_11DB) # 0-3.3V full range

# Active recipe task reference
recipe_task = None

# Shared sensor readings dictionary (starts with default off values)
sensor_data = {
    "vision": "none",
    "sound": "none",
    "button_a": "released",
    "button_b": "released",
    "potentiometer": 0
}

async def run_blocks(blocks):
    """Recursively execute compiled workflow blocks."""
    for block in blocks:
        action = block.get('action')
        
        if action == 'move':
            motor_name = block.get('motor')
            steps = int(block.get('steps', 0))
            speed = int(block.get('speed', 2))
            
            motor = motors.get(motor_name)
            if motor:
                motor.set_speed(speed)
                motor.move(steps)
                
                # Non-blocking wait for movement to complete
                while motor.is_moving:
                    await asyncio.sleep_ms(20)
                
        elif action == 'set_speed':
            motor_name = block.get('motor')
            speed = int(block.get('speed', 2))
            motor = motors.get(motor_name)
            if motor:
                motor.set_speed(speed)

        elif action == 'stop_all':
            for motor in motors.values():
                motor.stop()

        elif action == 'wait':
            duration = float(block.get('duration', 0.0))
            await asyncio.sleep(duration)
            
        elif action == 'loop':
            iterations = int(block.get('iterations', 1))
            body = block.get('body', [])
            for _ in range(iterations):
                await run_blocks(body)
                
        elif action == 'if':
            sensor_name = block.get('sensor')
            target_val = block.get('value')
            op = block.get('op', 'eq') # comparison operator: 'eq', 'gt', 'lt'
            body = block.get('body', [])
            
            current_val = sensor_data.get(sensor_name)
            
            # Match condition
            matched = False
            if op == 'eq':
                matched = (str(current_val) == str(target_val))
            elif op == 'gt':
                try:
                    matched = (float(current_val) > float(target_val))
                except: pass
            elif op == 'lt':
                try:
                    matched = (float(current_val) < float(target_val))
                except: pass
                
            if matched:
                await run_blocks(body)

async def execute_recipe(recipe):
    """Wrapper task for recipe execution that ensures cleanup on cancel."""
    global recipe_task
    try:
        print("Starting program execution...")
        await run_blocks(recipe)
        print("Program finished successfully.")
    except asyncio.CancelledError:
        print("Program execution stopped by user request.")
    finally:
        for motor in motors.values():
            motor.stop()
        recipe_task = None

async def execute_raw_code(code_str):
    """Wrapper task for raw MicroPython script execution that compiles and runs code in an async task."""
    global recipe_task
    try:
        print("Starting raw python execution...")
        # Indent the user's code to run it inside an async wrapper function
        indented_code = "\n".join("    " + line for line in code_str.split("\n"))
        wrapper = "async def run_user_code(motors, sensor_data, asyncio):\n" + indented_code
        
        # Create context dict and compile/execute definition
        env = {}
        exec(wrapper, globals(), env)
        
        # Execute the defined coroutine passing global objects
        await env['run_user_code'](motors, sensor_data, asyncio)
        print("Raw python finished successfully.")
    except asyncio.CancelledError:
        print("Raw python execution stopped by user request.")
    except Exception as e:
        print("Python execution error:", e)
    finally:
        for motor in motors.values():
            motor.stop()
        recipe_task = None

def run_recipe_callback(program):
    """
    Callback triggered by WebServer API endpoints to control the active task.
    Supports list recipes (Scratch blocks) and string raw code (MicroPython text).
    """
    global recipe_task
    
    # If program is None, stop the current program
    if program is None:
        if recipe_task:
            recipe_task.cancel()
            recipe_task = None
        return True
        
    # If a program is already running, return False (busy)
    if recipe_task is not None:
        return False
        
    # Start execution task in the background (detect type)
    if isinstance(program, str):
        recipe_task = asyncio.create_task(execute_raw_code(program))
    else:
        recipe_task = asyncio.create_task(execute_recipe(program))
    return True

async def poll_hardware_sensors():
    """Background loop that polls GPIO sensors and updates the state dictionary."""
    while True:
        # 0 = pressed (due to PULL_UP resistor wired to GND)
        sensor_data["button_a"] = "pressed" if btn_a.value() == 0 else "released"
        sensor_data["button_b"] = "pressed" if btn_b.value() == 0 else "released"
        
        try:
            # Read 16-bit ADC value (0 - 65535) and map to 0-100% dial range
            raw_adc = pot.read_u16()
            sensor_data["potentiometer"] = int((raw_adc / 65535) * 100)
        except Exception as e:
            pass
            
        await asyncio.sleep_ms(50)

async def main():
    print("Initializing systems...")
    
    # 1. Start Stepper Motor Background Loop tasks
    for motor in motors.values():
        asyncio.create_task(motor.run_loop())
    
    # 2. Start GPIO Hardware Sensors Background Poller
    asyncio.create_task(poll_hardware_sensors())
    
    # 3. Start Captive Portal DNS Server (Resolves all queries to ESP32 IP: 192.168.4.1)
    dns_server = DNSServer(ip="192.168.4.1")
    asyncio.create_task(dns_server.run())
    
    # 4. Start Web Server on port 80
    web_server = WebServer(motors, sensor_data=sensor_data, host="0.0.0.0", port=80, redirect_host="robot.com")
    await web_server.start(run_recipe_callback)
    
    # Keep the main loop alive and manage memory fragmentation
    while True:
        gc.collect()
        await asyncio.sleep(5)

# Start event loop
if __name__ == '__main__':
    try:
        asyncio.run(main())
    except KeyboardInterrupt:
        print("Program halted")

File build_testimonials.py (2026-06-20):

import urllib.request
import json
import re
import os
import sys

def fetch_comments():
    token = os.environ.get("GITHUB_TOKEN")
    if not token:
        print("No GITHUB_TOKEN provided, skipping testimonials")
        return []

    url = "https://api.github.com/graphql"
    query = """
    query {
      repository(owner: "sloev", name: "robo") {
        discussion(number: 2) {
          comments(last: 10) {
            nodes {
              author { login }
              body
              url
            }
          }
        }
      }
    }
    """
    
    req = urllib.request.Request(url, json.dumps({"query": query}).encode("utf-8"))
    req.add_header("Authorization", f"Bearer {token}")
    req.add_header("Content-Type", "application/json")
    
    try:
        response = urllib.request.urlopen(req)
        data = json.loads(response.read())
        return data["data"]["repository"]["discussion"]["comments"]["nodes"]
    except Exception as e:
        print(f"Error fetching comments: {e}")
        return []

def extract_image(body):
    # Try markdown
    md_match = re.search(r'!\[.*?\]\((.*?)\)', body)
    if md_match: return md_match.group(1), re.sub(r'!\[.*?\]\(.*?\)', '', body).strip()
    
    # Try HTML
    html_match = re.search(r'<img[^>]+src=["\']([^"\']+)["\']', body)
    if html_match: return html_match.group(1), re.sub(r'<img[^>]+>', '', body).strip()
    
    return None, body

def main():
    comments = fetch_comments()
    slides = []
    dots = []
    
    for i, c in enumerate(reversed(comments)):
        if not c: continue
        author = c["author"]["login"] if c.get("author") else "Anonymous"
        avatar_letter = author[0].upper() if author else "A"
        url = c["url"]
        body = c["body"]
        
        img_url, text = extract_image(body)
        if not img_url:
            continue # Only feature comments with images
            
        # Truncate text
        text = text.replace('\r', '').replace('\n', ' ')
        if len(text) > 300: text = text[:297] + "..."
        if not text: text = "Check out this amazing build!"
        
        active_class = "active" if len(slides) == 0 else ""
        
        slide_html = f"""
        <div class="carousel-slide {active_class}">
          <div class="testimonial-card">
            <img src="{img_url}" alt="Community Build" class="testimonial-img">
            <div class="testimonial-content">
              <blockquote class="testimonial-quote">"{text}"</blockquote>
              <a href="{url}" target="_blank" class="testimonial-link">Read original post ↗</a>
            </div>
          </div>
        </div>
        """
        slides.append(slide_html)
        dots.append(f'<div class="carousel-dot {active_class}" data-index="{len(slides)-1}"></div>')

    # Add fallback placeholder if no valid comments found
    if not slides:
        print("No valid comments with images found. Keeping placeholder.")
        return

    # Add the "You're Next" slide
    slides.append(f"""
        <div class="carousel-slide">
          <div class="testimonial-card">
            <div class="testimonial-img" style="background: var(--surface-light); display: flex; align-items: center; justify-content: center; font-size: 4rem;">🛠️</div>
            <div class="testimonial-content">
              <blockquote class="testimonial-quote">"Your creation could be featured here! Share your ESP32 robot, crane, or catapult in our GitHub Discussions."</blockquote>
              <a href="https://github.com/sloev/robo/discussions/2" target="_blank" class="testimonial-link">Post your build ↗</a>
            </div>
          </div>
        </div>
    """)
    dots.append(f'<div class="carousel-dot" data-index="{len(slides)-1}"></div>')

    # Read public/index.html
    html_path = "public/index.html"
    try:
        with open(html_path, "r") as f:
            content = f.read()
    except Exception as e:
        print(f"Error reading index.html: {e}")
        return

    # Replace slides
    track_pattern = re.compile(r'(<div class="carousel-track" id="testimonial-track">).*?(</div>\s*<div class="carousel-nav")', re.DOTALL)
    new_track = r'\1' + "\n" + "".join(slides) + "\n" + r'\2'
    content = track_pattern.sub(new_track, content)

    # Replace dots
    nav_pattern = re.compile(r'(<div class="carousel-nav" id="carousel-nav">).*?(</div>\s*</div>\s*</div>\s*<h2 class="section-title">)', re.DOTALL)
    new_nav = r'\1' + "\n" + "".join(dots) + "\n" + r'\2'
    content = nav_pattern.sub(new_nav, content)

    with open(html_path, "w") as f:
        f.write(content)
    print("Successfully updated testimonials in index.html!")

if __name__ == "__main__":
    main()

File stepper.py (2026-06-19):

import asyncio
from machine import Pin

class Stepper:
    def __init__(self, pin_ids, step_delay_ms=2):
        """
        Initialize the stepper motor with 4 pin numbers.
        Sequence of pins should match IN1, IN2, IN3, IN4 on the ULN2003 board.
        """
        self.pins = [Pin(p, Pin.OUT) for p in pin_ids]
        self.target_position = 0
        self.current_position = 0
        self.step_delay_ms = step_delay_ms
        self.running = False
        self.step_index = 0
        
        # 8-step half-stepping sequence
        self.sequence = [
            [1, 0, 0, 0],
            [1, 1, 0, 0],
            [0, 1, 0, 0],
            [0, 1, 1, 0],
            [0, 0, 1, 0],
            [0, 0, 1, 1],
            [0, 0, 0, 1],
            [1, 0, 0, 1]
        ]
        self.release()

    def release(self):
        """Release coils to save power and prevent overheating."""
        for pin in self.pins:
            pin.value(0)

    def move(self, steps):
        """Set relative movement target in steps (positive or negative)."""
        self.target_position += steps

    def move_to(self, position):
        """Set absolute target position."""
        self.target_position = position

    def stop(self):
        """Cancel current movement immediately."""
        self.target_position = self.current_position
        self.release()

    def set_speed(self, delay_ms):
        """Set the delay between steps in milliseconds (lower is faster)."""
        self.step_delay_ms = max(1, delay_ms)

    @property
    def is_moving(self):
        return self.current_position != self.target_position

    async def run_loop(self):
        """Background coroutine that handles stepping to the target position."""
        self.running = True
        try:
            import time
            while self.running:
                if self.current_position != self.target_position:
                    direction = 1 if self.target_position > self.current_position else -1
                    
                    # Dynamically batch steps to overcome asyncio event loop overhead.
                    # We block synchronously for up to ~15ms to achieve physical motor speed limits.
                    batch_size = max(1, 15 // self.step_delay_ms)
                    steps_to_take = min(abs(self.target_position - self.current_position), batch_size)
                    
                    for i in range(steps_to_take):
                        self.step_index = (self.step_index + direction) % 8
                        
                        # Apply coil sequence
                        vals = self.sequence[self.step_index]
                        for pin, val in zip(self.pins, vals):
                            pin.value(val)
                            
                        self.current_position += direction
                        
                        # Use precise hardware sleep between batched steps
                        if i < steps_to_take - 1:
                            time.sleep_us(self.step_delay_ms * 1000)
                            
                    # Yield to other tasks for the duration of the final step
                    await asyncio.sleep_ms(self.step_delay_ms)
                else:
                    self.release()
                    # Sleep when idle to avoid hogging CPU
                    await asyncio.sleep_ms(10)
        except asyncio.CancelledError:
            self.stop()
            raise

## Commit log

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2026-06-19 fix: batch motor steps synchronously to bypass asyncio event loop overhead and maximize stepper speed
    [stepper.py]
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2026-06-20 fix(scad): add part colors, fix lid stud bounds, and mockup electronics for showcase render
    [lego_robot_vehicle.scad]
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2026-06-20 fix(scad): correct 28BYJ-48 motor bays for precise horizontal layout with 35mm horizontal flange pilot holes and cable routing gaps
    [lego_robot_vehicle.scad]
2026-06-20 fix(scad): change ULN2003 mounts from vertical to flat snap trays for perfect wire routing
    [lego_robot_vehicle.scad]
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2026-06-20 ci: replace deprecated meshlabserver with openctm-tools for robust STL to OBJ conversion
    [vehicle_couplers.stl]
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2026-06-20 feat(scad): replace heavy phone stand with an ultra-minimal elastic band clamp system integrated into chassis
    [lego_robot_vehicle.scad]
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2026-06-20 feat(scad): replace floating phone jaw with an integrated T-slot sliding rail mechanism and update assembly docs
    [lego_robot_base.scad, lego_robot_phone_clamp.scad]
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2026-06-20 feat(scad): drastically increase phone slider T-slot stability and remove delicate sliding lid bridge hole
    [lego_robot_base.scad, lego_robot_phone_clamp.scad, lego_robot_showcase.scad]
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2026-06-20 chore: clean up mistakenly committed downloaded-artifacts folder and fix showcase clamp duplicate
    [lego_robot_showcase.scad, vehicle_base.obj, vehicle_couplers.obj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]
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2026-06-20 fix(cad): resolve non-manifold STL export by sinking all internal mounts 0.1mm into the floor
    [lego_robot_base.scad]
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2026-06-20 fix(ci): eliminate silent render failures by dropping OBJ for direct STL
    The STL->OBJ step (ctmconv) was failing to parse OpenSCAD's STL for every
    part in CI, the failure was swallowed (jobs went green), and stale committed
    .obj files were re-shipped -- so the website served outdated geometry and the
    phone clamp 404'd (the only part with no stale .obj to mask the failure).
    - Drop ctmconv/OBJ entirely; serve OpenSCAD-native STL to the Three.js viewer
    (STLLoader) and as the download/zip format.
    - New ci_render_part.sh: render STL headless (exit codes propagate) and hard-gate
    on non-empty + manifold (Simple: yes) + no OpenSCAD ERROR.
    - render.yml: set -euo pipefail, drop `git pull || true`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
    [vehicle_base.obj, vehicle_couplers.obj, vehicle_couplers.stl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]
2026-06-20 fix(cad): flat floor, real motor shaft exit, taller clamp, flush lid, LEGO stud height
    The web viewer was showing a stale base.obj; now that it loads the live base
    STL these real defects in the current geometry are visible and fixed:
    - base: remove the lower full-width Technic-hole row that sliced the
    electronics-bay floor into strips -> floor is now flat (volumes 12 -> 4).
    - base: lengthen the motor U-slot shaft channel (h 11 -> 20) so it pierces the
    outer wall and the 28BYJ-48 shaft/coupler can actually exit the side.
    - phone clamp: lengthen slider 130 -> 185mm and raise the jaw so it reaches the
    top of a 6"/~163mm phone with adequate T-slot engagement.
    - lid: stud height 1.9 -> 1.6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
    [lego_robot_base.scad, lego_robot_lid.scad, lego_robot_phone_clamp.scad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]
2026-06-20 feat(viewer/cad): brighter base, captive inlaid couplers, electronics in viewer
    - Base color brightened (#2c3e50 -> #5b9bd5) in base.scad, showcase, viewer.
    - Couplers placed captive/inlaid at the wall (x=+-41.2): the wide flange is
    trapped inside the wall (flange groove) and only the axle socket shows
    outside, like a normal Technic hole. Reverted the earlier outer counterbore
    (wrong side) and the outside-the-wall viewer placement.
    - Viewer: added non-printed internals for realism -- grey 28BYJ-48 motors and
    purple ULN2003 + ESP32-S2 boards, exploding down with the base.
    - Viewer: phone clamp explodes well clear of the lid (no intersection).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
    [lego_robot_base.scad, lego_robot_showcase.scad]
2026-06-20 fix(cad): real 1-unit (8mm) side walls, Technic holes on grid + bevels, solid phone shelf
    - Side walls are now a true LEGO unit (8mm). The old "thickeners" were deleted
    by the inner-cavity cut (width-2*1.6), leaving 1.6mm walls and a loose lid;
    the cavity is now inset 8mm on X so the lid (79.6) seats in an 80mm bay and
    Technic holes / motor mounts / couplers sit in solid wall.
    - Technic holes moved to the true LEGO grid height (5.8+3*9.6 = 34.6mm) with
    Ø6.2 x 0.9 bevels on each outer face, like a real Technic brick.
    - Phone resting shelf rebuilt: thin 3mm cantilevered lip -> 6mm solid full-width
    shelf fused to the front wall with triangular gusset webs + taller retaining
    wall (n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
    [lego_robot_base.scad, lego_robot_common.scad]
2026-06-21 feat: accurate 28BYJ-48 motors, wider phone cradle, solid back wall
    - Viewer + showcase: detailed single-colour 28BYJ-48 motors (body can, offset
    flat-D shaft + boss, two mount ears with Ø4 holes 35mm apart, cable connector
    + wires), mounted to the inside walls.
    - Phone cradle widened: full-width flat back-rest + ~14mm slot so a real phone
    (with case) actually fits; deep solid shelf.
    - Lid rail groove no longer cuts a slit through the back (USB-C) wall; the solid
    wall is the lid's end stop.
    [lego_robot_base.scad, lego_robot_showcase.scad]
2026-06-21 feat(cad): print-friendly couplers, flat solid base bottom, extra Technic rows
    Printability pass for support-free FDM:
    - Couplers: Ø12 captive ring now at the motor end stepping down to the Ø8 axle
    nose, so the part prints standing on its wide end (widest->narrowest) with no
    overhang, while staying captive behind the wall.
    - Base: removed the bottom Lego cavity -> flat solid underside prints flat on
    the bed with no bridge and a stronger floor.
    - Base: added two more Technic-hole rows (15.4 / 25.0 / 34.6mm) on the side
    walls to replace the removed underside attachment. Lid still prints flat.
    [lego_robot_base.scad, lego_robot_couplers.scad, vehicle_couplers.stl]
2026-06-21 fix(cad): restore correct coupler flat-D socket (no side holes)
    The print-friendly rewrite accidentally moved the flat-D socket's flat cuts into
    the outer difference, so they cut through the coupler body (side holes) and
    malformed the shaft socket. Nest the flat cuts in a local difference with the
    Ø5.2 socket cylinder again, as in the original, so they only shape the socket.
    Keeps the Ø12->Ø8 print-standing profile.
    [lego_robot_couplers.scad, vehicle_couplers.stl]
2026-06-21 fix(cad): match motor mount + wall U-slot to the new captive coupler
    The new coupler has its flat-D socket at the inboard Ø12 end, so the motor shaft
    must end inside the cavity at that socket (only the coupler's Ø8 nose + the LEGO
    axle use the Ø8.5 wall hole). Changes:
    - Motor mount is now a friction cradle in the cavity (body centred at x=±17.5),
    no wall screws -- shaft plugs straight into the captive coupler.
    - Removed the vestigial Ø12.5 central flange groove from the wall U-slot (the
    Ø12 ring is captive simply by being inboard of the Ø8.5 hole).
    - Fixed the motor model's flat-D shaft (flats now actually cut; Ø5 x 6mm per the
    28BYJ-48 diagram) and repositioned motors/coupler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
    [lego_robot_base.scad, lego_robot_showcase.scad]
2026-06-21 feat(cad): wall-mounted motors + coupler pockets; horizontal V-clamp v1
    Motor/coupler/wall (per feedback):
    - Technic holes now pierce the side WALLS ONLY (not across the whole cavity) and
    are skipped over the front motor zone.
    - Motor mounts face-on, SCREWED to the wall (Ø2.5 pilots, ears 35mm apart); the
    cradle is fused to the wall and widened for strength.
    - Coupler sits in a Ø12.5 circular pocket in the inner wall (no top drop-slot);
    Ø8.5 hole through the wall for its nose + the LEGO axle (Ø12 ring captive).
    Phone holder v1 (horizontal clamp, clamp-first):
    - Bottom V-rest groove (phone-width) self-centres any thickness.
    - Fixed RIGHT V-jaw + adjustable LEFT V-jaw (phone_clamp),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
    [lego_robot_base.scad, lego_robot_phone_clamp.scad, lego_robot_showcase.scad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]
2026-06-21 feat(cad): chassis reorg -- shorter + taller, ULN boards on inner walls
    - Dimensions: length 128->96, height 48->57.6 (taller lets the phone clamp grip
    higher; shorter because the floor no longer holds the ULN boards). Parametrised
    the lid rail height (lid_z) and the lid length so the lid tracks the chassis.
    - ULN2003 boards now stand vertically on the inner side walls (slide-in saddle
    ribs); ESP32 sits flat on the floor between them. Wall Technic holes reworked:
    full top row (44.2, above the boards) + rear lower rows, motor zone kept solid.
    - Motor cradle is now open saddle supports only (does NOT enclose the motor), so
    the motor can be slid in to seat its shaft in the wall-pocket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
    [lego_robot_base.scad, lego_robot_common.scad, lego_robot_lid.scad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]
2026-06-21 feat(cad): snap-in PCB mounts (ESP32 + ULN)
    - New reusable snap_pcb_mount(): corner standoffs + flexible edge snap hooks the
    board clicks into (no screws). Used for the ESP32-S2 Mini on the floor.
    - ULN wall mounts get a top snap lip (plus the guide ribs + bottom ledge) so the
    vertical boards click flat against the inner wall.
    [lego_robot_base.scad]
2026-06-21 fix(cad): rework V-clamp -- V-rest carries phone, fused fixed jaw, real moving rail
    Fixes the three v1 bugs:
    - The side-jaw V-notches are constant-section vertical prisms (no horizontal
    ledge), and the bottom V-rest is now wider than the phone (±40) -- so the
    phone slides straight down onto the V-rest, which carries its weight.
    - The fixed RIGHT jaw is a solid buttress fused to the front wall over its full
    height (no gap / weak point).
    - The moving LEFT jaw's foot now rides a real pedestal rail at the phone plane,
    with rear elastic pegs on both jaws (band runs hidden behind the phone) that
    pull it inward to clamp.
    [lego_robot_base.scad, lego_robot_phone_clamp.scad, vehicle_phone_clamp.stl]
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2026-06-21 fix: motor/coupler Y in viewer, ESP32 USB-C to back wall, flush fixed jaw
    - Viewer motors + couplers were at the old motor_y (44); moved to 30 so they no
    longer sit in the front wall / clamp area.
    - ESP32 moved to the back of the floor so its USB-C lines up with the back-wall
    pass-through (passthrough resized/aligned). Updated base, showcase, viewer.
    - Fixed clamp jaw now spans the full wall thickness (x 36..48), flush with and
    fused to the outer wall -- no gap. Elastic hooks on both jaw backs at a matching
    height so the band runs straight across behind the phone.
    [lego_robot_base.scad, lego_robot_phone_clamp.scad, lego_robot_showcase.scad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]
2026-06-21 fix(cad): solid half-tube motor cradle; captive T-slot clamp jaw + band shown
    - Motor cradle is now ONE solid open-top half-tube (Ø29 bore) per motor, not two
    ribs -- the motor drops straight in. Motor moved to motor_y=26 so the front
    mounting ear (motor_y+17.5) stays inside the cavity (was poking the front wall).
    Viewer motors/couplers follow (y=26).
    - Phone clamp: the moving jaw now has a real captive T-FOOT that rides a T-slot
    rail in the pedestal (held to the chassis, slides in X to fit any width). The
    bottom V-rest still carries the phone; rear hooks on both jaws take the rubber
    band that squeezes them together. Showcase now renders the band + a phone so
    the mechanism is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
    [lego_robot_base.scad, lego_robot_common.scad, lego_robot_phone_clamp.scad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]
2026-06-21 fix(cad): move clamp elastic hooks down to the groove line (anti-jam)
    The band hooks were ~15mm above the slide groove, so the pull cocked the moving
    jaw and would jam it. Move both hooks (fixed/chassis jaw + moving jaw) down to
    just above the rail (z~15), at the same Y, so the band pulls in-line with the
    slide axis. The band attaches chassis-side on the fixed jaw and clamp-side on
    the moving jaw, behind the phone.
    [lego_robot_base.scad, lego_robot_phone_clamp.scad, lego_robot_showcase.scad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]
2026-06-21 fix: reconnect clamp elastic hook (was a floating piece); WebGL fallback
    - The moving-jaw rear hook sat 1mm behind the post (a separate 3rd volume / loose
    piece). Anchor it into the post so the jaw is one solid part again.
    - viewer.js: wrap in an IIFE and, when WebGL can't initialise, show the static
    render and return instead of rethrowing an uncaught error. Guard missing DOM
    nodes too.
    [lego_robot_phone_clamp.scad, vehicle_phone_clamp.stl]
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2026-06-21 fix(cad): lower motor cradle below ears; ULN snap fingers; fixed-jaw V-notch to V-rest
    - Motor cradle top now stops ~4mm below the ear line so the motor can be slid
    into its coupler without the ears fouling the cradle.
    - ULN wall mounts get real flexible snap-in fingers (board clicks in), moved back
    to uy=-16 so the motor's rear ear (y~8.5) has clearance. Overlapped into the
    wall/ledge so the mount is one solid part (was leaving floating pieces).
    - Fixed clamp jaw V-notch now extends down to the bottom V-rest (removed the flat
    blocker that stopped the phone reaching the V-groove on that side).
    [lego_robot_base.scad]
2026-06-21 feat(clamp): phone stands in front of the wall, rail-in-wall jaws, band behind
    Rework the phone clamp to the confirmed architecture: the phone leans on the
    front clamp-wall, bottom edge in a V-lip shelf. Two V-jaws grip its side edges
    and ride a horizontal T-slot rail cut THROUGH the wall (fixed-right fused to the
    chassis, moving-left a separate part that telescopes out the side to load). The
    rubber band runs BEHIND the wall in the cavity gap (clear of the motors) on
    accessible posts at rail height, so its pull is in-line with the slide and the
    jaw can't cock and jam.
    Both parts render manifold (Volumes:2). Showcase + Three.js viewer updated to the
    new layout (phone in front, band behind at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
    [lego_robot_base.scad, lego_robot_phone_clamp.scad, lego_robot_showcase.scad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]
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2026-06-22 redesign phone clamp: T-slot rail, fixed V-notch, accessible band pegs
    Four bugs eliminated:
    1. V-notch flat wall: base of V-notch polygon now flush with jaw inner face
    (x=±35), no 1mm stub. Both jaws: [[44,0],[35,-9],[35,9]].
    2. Rectangular slot → proper T-slot: neck (y=54-58, z=23-29) + undercut
    (y=51-54, z=20-32) milled into wall front face. Tongue flanges lock
    behind the z<23 / z>29 ledges — jaw cannot pull out in Y.
    3. Tongue redesigned as true T-profile: neck 3.6×5.6mm + two 2.6×2.6mm
    flanges, 65mm long, 0.2mm clearance per side. Slides in X only.
    4. Band posts moved from hidden cavity (y=44) to jaw front faces:
    forward-facing mushroom pegs (rotate([-90,0,0]))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
    [lego_robot_base.scad, lego_robot_phone_clamp.scad, lego_robot_showcase.scad]
2026-06-22 Fix non-manifold geometry: eliminate coplanar faces in phone clamp union (#4)
    Three coplanar faces caused render-base CI to report Simple: no.
    Overlaps added (1-2mm) so all geometry properly intersects rather than
    touching at exact shared faces in a CSG union:
    - Rail extension now x=-96..-46 (2mm into clamp-wall, was flush at x=-48)
    - Shelf now y=57-71 (1mm into wall front face, was flush at y=58)
    - Fixed jaw now z=7-36 (1mm into shelf, was flush at z=8)
    - Band pegs shifted 1mm inward on both jaws to sit inside jaw body
    - V-groove and V-notch cut extents updated to match new jaw dimensions
    Claude-Session: https://claude.ai/code/session_01QZDUA8BJtQFRjedTjrAcJX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
    [lego_robot_base.scad, lego_robot_phone_clamp.scad, lego_robot_showcase.scad]
2026-06-22 Fix non-manifold: replace rail+wall two-cube junction with single wide cube (#5)
    The original CI failure (Simple: no) was caused by T-junctions in CGAL's
    Nef polyhedra union: two cubes sharing the same y/z extent but different
    x-ranges create internal edges at their x-boundary that violate the
    manifold condition.
    Fix: merge clamp-wall (x=-48..+48) and rail extension (x=-96..-48) into
    a single 144mm-wide cube (x=-96..+48, y=48-58, z=0-36). No internal
    junctions possible in a single primitive.
    Also restore shelf/jaw positions to match the original passing design
    (3-7mm overlap into wall body) and keep jaw front 1mm past shelf front
    to eliminate the y=69 coplanar face between them. Band peg b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
    [lego_robot_base.scad, lego_robot_phone_clamp.scad, lego_robot_showcase.scad]
2026-06-23 Mirror clamp to right side, fix T-tongue profile and V-groove alignment (#6)
    - Mirror entire phone clamp system from left to right side: rail extension
    moves from x=-96..-48 to x=+48..+96, fixed jaw from x=+40 to x=-40,
    moving jaw from x=-40 to x=+40 with tongue extending rightward to x=+100,
    T-slot from x=-96..+10 to x=-10..+96
    - Replace two disconnected T-tongue flanges with a single full-height
    undercut body (z=20-32, 12mm) matching the complete T-slot profile
    - Extend V-lip groove from 80mm (x=-40..+40) to 92mm (x=-46..+46) so the
    moving jaw at x=+35-45 no longer hits the flat shelf top at z=8
    - Trim jaw body Y depth from 18mm to 15mm starting at y=fy+6 to reduce
    V-notch over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
    [lego_robot_base.scad, lego_robot_phone_clamp.scad]
2026-07-03 Fix phone clamp telescoping direction and manifold issues
    - Reversed T-tongue to extend leftward from moving jaw so jaw itself can telescope outward without the clamp wall extending out.
    - Avoided coplanar non-manifold faces by slightly overlapping the tongue components with the jaw grip finger.
    - Moved moving jaw grip finger slightly forward to prevent clipping inside the chassis front wall when closed.
    - Removed outward right rail extension from base chassis.
    - Adjusted T-slot neck and undercut in base chassis to fit the left-extending tongue.
    - Updated clamp.md source of truth documentation.
    [lego_robot_phone_clamp.scad, vehicle_base.stl, vehicle_phone_clamp.stl]
2026-07-03 Improve robustness and fit of 3D-printed AI phone clamp and chassis
    - Extends the T-tongue deeply into the jaw block and adds a solid filler block for a robust corner junction.
    - Expands the T-tongue vertical height to the full height of the clamp (down to z=7), and updates the corresponding base T-slot cut.
    - Restores the bottom flange of the T-slot geometry by setting the neck start to z=10.
    - Fixes the V-notch extrusion to cut fully through the new extended tongue base.
    - Reduces the depth of the cradle rest V-groove to leave more solid material in the base.
    - Truncates the overhanging chassis rail extension, restricting the slot entirely to the base width.
    - Removes the conflicting secur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
    [lego_robot_base.scad, lego_robot_lid.scad, lego_robot_phone_clamp.scad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]
2026-07-03 Implement first-person TFJS object detection for AI Car Mode
    - Completely replaced the contradictory overhead "background differencing" logic in `app.js` with a lightweight, offline TensorFlow.js COCO-SSD object detection pipeline.
    - The car now actively reacts to objects in front of it (acting like a toy Tesla), backing up and turning if a bounding box occupies >40% of its vision, or stopping for specific classes like "person" or "stop sign".
    - Downloaded `tf.min.js`, `coco-ssd.min.js`, and the required COCO-SSD model shards into local `static/lib` and `static/models` directories to guarantee true offline capability via the captive portal.
    - Updated `web_server.py` to serve these new static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
    [web_server.py]
2026-07-03 Fix real tongue/wall collision in phone clamp T-slot, add print tolerance
    Boolean-intersected the moving jaw against the chassis and found the parts
    actually overlap in three places (not just visually similar to the reported
    symptoms, verified with OpenSCAD CSG intersection):
    - The tongue's X span (-30..45) reached 20mm past the chassis's actual
    T-slot cavity (-10..48) into solid, un-milled wall (~2.8cm^3 overlap) --
    a prior edit shrank the cavity and dropped the rail extension but never
    updated the tongue to match.
    - The tongue/finger "filler" corner block used the full undercut height in
    a Y-band where only the shallower neck cavity exists, punching into solid
    material above/bel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
    [lego_robot_base.scad, lego_robot_common.scad, lego_robot_phone_clamp.scad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]
2026-07-03 Improve print quality: fix a floating-support regression, teardrop the functionally-sensitive holes, and ship the coupler pre-oriented
    Investigated printability across all four shipped parts by rendering,
    boolean-checking, and slicing them into thin Z-slabs (not just reading the
    code) to look for overhangs and unsupported regions.
    Found and fixed:
    - Regression from the last PR: raising the grip finger to clear the V-lip
    shelf left it floored above where it connects to the tongue, so it printed
    as an unsupported floating island from z=8.3 to 10.3 (confirmed by slicing
    the model and seeing it as a disconnected blob). Reflooring it at
    slot_neck_z0 + clamp_tol instead of shelf_top_z +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
    [lego_robot_base.scad, lego_robot_common.scad, lego_robot_couplers.scad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]
2026-07-04 Revert teardrop holes; fix website viewer for the now-rotated coupler STL
    Revert the Ø12.5/Ø8.5 teardrop holes in the chassis back to plain round
    cylinder() holes, and remove the now-unused teardrop_hole() helper.
    The motor coupler's standalone STL export stays rotated 90° (prints
    standing on its wide end, per the existing module comment), but
    website/viewer.js loads that same STL and positions/rotates it in the
    assembled 3D scene assuming its old, un-rotated orientation ("the model's
    default orientation points D-socket to +X") -- so the print-orientation
    change silently broke the website's assembled view.
    Fixed by adding an stlRot parameter to loadPart() that undoes the print
    rotation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
    [lego_robot_base.scad, lego_robot_common.scad]
2026-07-04 Regenerate vehicle_base.stl and vehicle_models.zip after rebase
    Binary artifacts conflicted during the rebase onto the latest master and
    were resolved by taking this branch's version, then rebuilt fresh from
    source here to guarantee they match the current lego_robot_base.scad
    exactly rather than relying on the conflict resolution alone.
    [vehicle_base.stl]
2026-07-04 Reinforce V-notches, fix exploded-view realism, unblock Pages deploy
    Three independent fixes from user feedback on the live preview:
    1. Revert the teardrop holes from the last change (per explicit request) --
    plain cylinder() holes again in lego_robot_base.scad, teardrop_hole()
    helper removed from lego_robot_common.scad.
    2. Reinforce the V-notches: the fixed jaw, moving jaw, and V-lip groove all
    had their tip within 1-3mm of the outer wall with a sharp interior point
    -- both a thin wall and a stress concentrator right behind it, prone to
    snapping under a side load. Added a shared rounded_notch_2d() helper
    (hull() of a real circle at the tip with two near-zero-radius circl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
    [lego_robot_base.scad, lego_robot_common.scad, lego_robot_phone_clamp.scad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]
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
